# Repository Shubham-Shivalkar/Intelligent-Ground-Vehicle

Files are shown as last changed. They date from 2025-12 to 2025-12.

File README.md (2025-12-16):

# Intelligent-Ground-Vehicle
Intelligent Ground Vehicle (IGV) is an autonomous rover developed for ROBOFEST Gujarat, designed to navigate complex terrains using a modified rocker suspension and ROS2-based autonomy. It integrates LiDAR, RGB-D vision, GNSS, and SLAM for reliable, collision-free navigation

📌 Overview

The Intelligent Ground Vehicle (IGV) project focuses on the design and development of an autonomous rover capable of navigating complex, unstructured terrains with minimal human intervention. Developed for the ROBOFEST Gujarat – Ground Vehicle Category, the rover demonstrates robust mechanical design, advanced perception, and autonomous navigation using ROS2-based software architecture.
This project addresses real-world challenges in autonomous navigation, where robots must operate reliably in cluttered, constrained, and dynamic environments, such as disaster zones, agricultural fields, and outdoor terrains.

🎯 Objectives
- Design a stable and lightweight rover platform for rough terrain traversal
- Achieve collision-free autonomous navigation across multi-stage obstacle courses
- Integrate sensor fusion, SLAM, and path planning using ROS2
- Validate performance through simulation (Gazebo + RViz) and real-world testing

  🏁 Competition Context

The Ground Vehicle Category consists of four progressive stages, each increasing in obstacle density and terrain complexity. Performance is evaluated based on:
- Collision-free navigation success rate
- Shortest traversal time
- Autonomy, robustness, and reliability
  
🛠️ Mechanical Design

- Suspension System: Modified Double Rocker Mechanism
- Chassis Material: Aluminum Alloy 6063-T6 (extrusion grade)

- Dimensions:

  - Length: 83.8 cm

  - Width: 69 cm

  - Height: 60 cm

- Terrain Capability:

  - Climbs slopes up to 45°
  - Maintains continuous wheel–ground contact
- Validation:
  - FEA confirms max deformation ≈ 0.0012 mm
  - Factor of Safety: 2.0 – 2.5
    
⚙️ Electronics & Sensors

- Low-Level Controller: Custom ESP32-S3 PCB

- High-Level Computer: NVIDIA Jetson Orin Nano

- Sensors:

  - YDLIDAR G2 (360° LiDAR)

  - Intel RealSense D435i (RGB-D + IMU)

  - MPU-9250 (9-axis IMU)

  - GNSS (u-blox M10)

  - Wheel Encoders (600 PPR)

🤖 Software Architecture

- Framework: ROS2

- Core Modules:

  - Sensor fusion (EKF)

  - 2D/3D SLAM (Cartographer, RTAB-Map)

  - Navigation stack (Nav2)

- Operating Modes:

  - Manual (PS5 controller)

  - Semi-autonomous

  - Fully autonomous

🧪 Simulation & Digital Twin

A Gazebo-based digital twin was developed to validate:

- Line following (Stage 1)

- Obstacle avoidance

- Ramp climbing

- Dynamic obstacle handling

Visualization and debugging were performed using RViz2 and RQT.

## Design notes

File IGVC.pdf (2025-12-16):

- Type of Robot: Autonomous Rover[IGV]
- Link of CAD : https://drive.google.com/drive/folders/1Fbs--0POYBewVTIGlXbTmj3GZvEJPO7q
- Robot Assembly Design (Proposed Diagram): Drawing each part of the robot is preferred as an attachment. (CAD drawings are preferred) (400 words)
NASA’s Mars missions demonstrated the versatility of the rocker-bogie in Curiosity and Perseverance, and by following the detailed guidelines and tasks provided by GUJCOST, we reengineered the concept into a 4-wheel rover with a rocker-type suspension and a differential stabilizer bar. This configuration reduces weight and kinematic complexity while preserving terrain adaptability, enabling traversal over hard rock, loose soil, and slopes up to 45°. The stabilizer minimizes chassis roll, ensuring continuous wheel–ground contact, higher traction efficiency, and a stable platform for autonomous sensing and navigation.
- The rocker mechanism consists of two rocker arms joined at a central pivot, designed at a 90° orientation to minimize induced stresses during terrain traversal.
- The overall dimensions of the rover are 83 × 68 × 60 cm (L × W × H), making it compact yet stable for IGVC field navigation.
- This geometry distributes loads evenly, reducing strain concentration and chances of permanent deformation in the chassis.

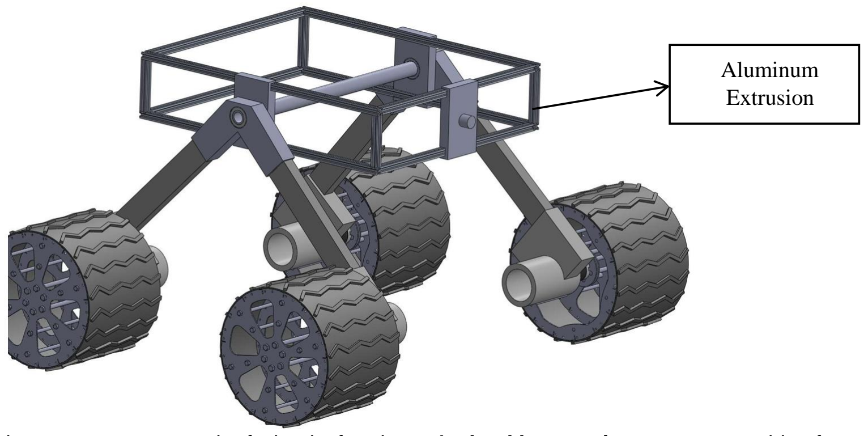
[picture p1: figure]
Aluminum Extrusion

- Each rocker arm supports a pair of wheels, forming a 4-wheel locomotion system capable of negotiating ramps, bridges, and uneven terrain.
- The two rockers are connected via a differential stabilizer bar, which balances the motion between left and right sides.
- The stabilizer ensures that when one side rises over an obstacle, the opposite side compensates, keeping the chassis level
- This enhances stability on slopes up to 45°, critical for ramps and dual incline sections in the IGVC arena.
- The mechanism enables alternate working of both rockers, distributing impact forces and maintaining continuous wheel contact with the ground.
- Reduced chassis oscillation improves sensor accuracy for localization, obstacle detection, and QR/AR code scanning during autonomous navigation.

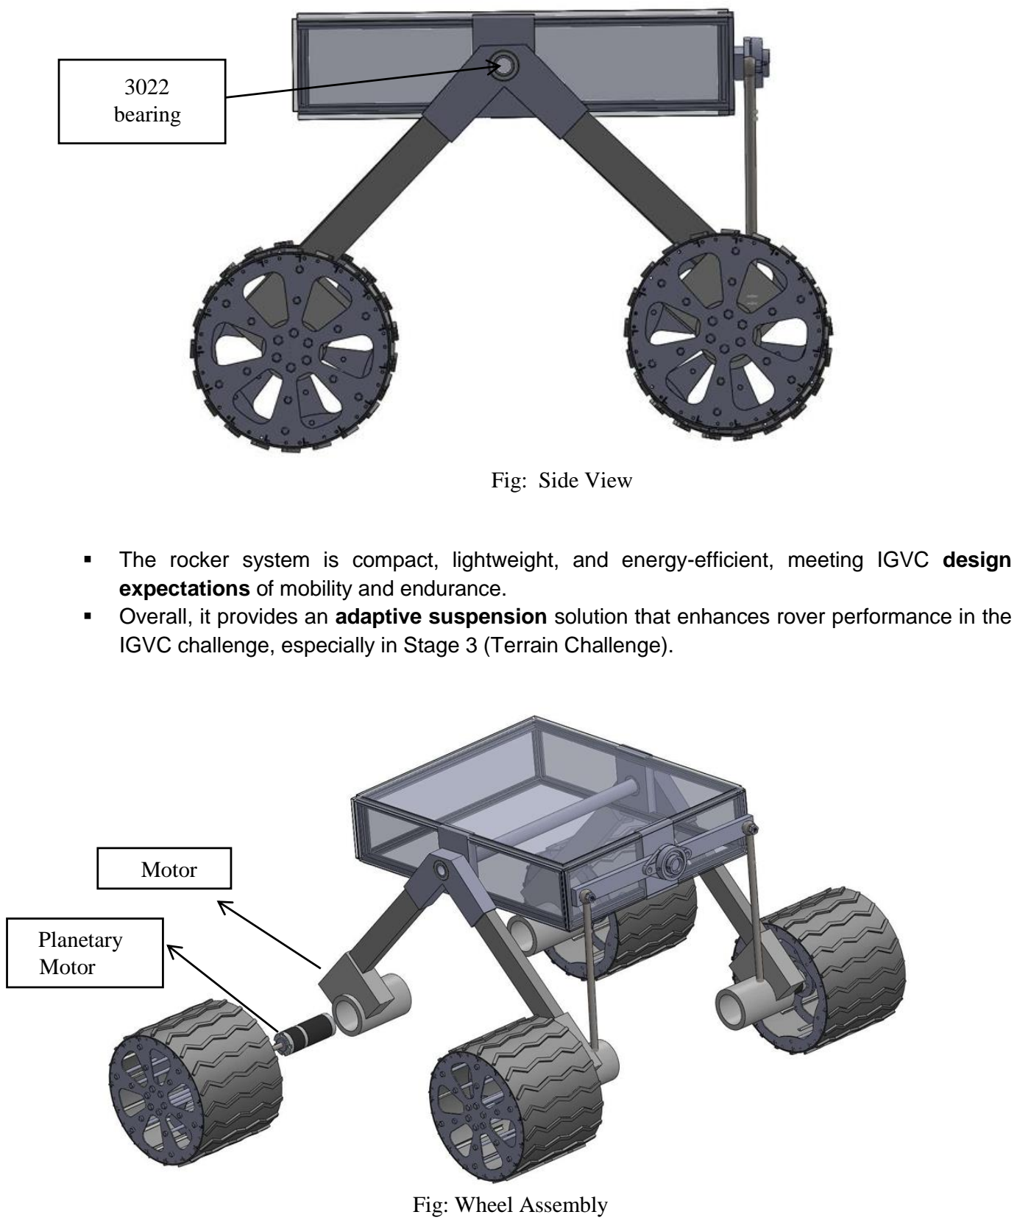
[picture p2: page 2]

Fig: Side View

- The rocker system is compact, lightweight, and energy-efficient, meeting IGVC design expectations of mobility and endurance.
- Overall, it provides an adaptive suspension solution that enhances rover performance in the IGVC challenge, especially in Stage 3 (Terrain Challenge).

Fig: Wheel Assembly

3022
bearing

Motor

Planetary
Motor

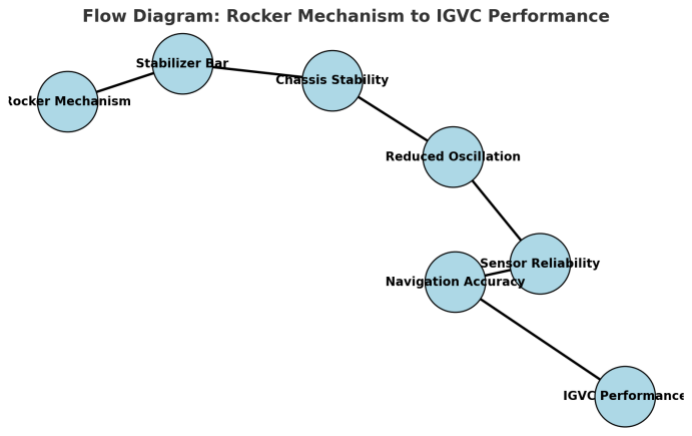
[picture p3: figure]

- Design specifications
- The rover is designed with compact dimensions to maintain stability while fitting within IGVC arena constraints.
- Length (83.81 cm) ensures longitudinal balance, Width (69 cm) prevents toppling, and Height (60 cm) allows mounting of sensors at optimal levels.

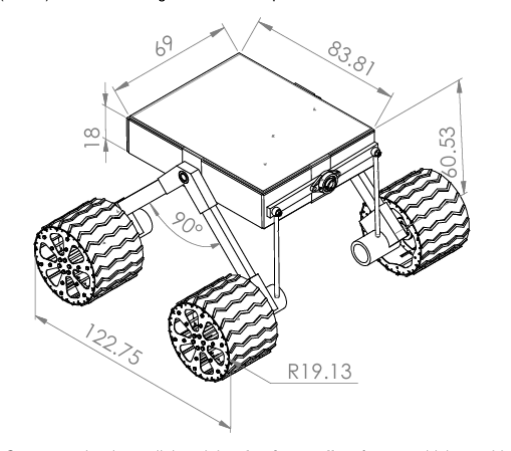
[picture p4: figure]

- Constructed using a lightweight aluminum alloy frame, which provides strength-to-weight efficiency. Integrated with a rocker-stabilizer suspension system for improved terrain adaptability.
- Suspension Mechanism Rocker arms are joined at 90° orientation, connected via a differential stabilizer bar. This ensures one side compensates for the other, reducing oscillations and keeping the chassis balanced.
- The rover can climb and descend ramps with inclines up to 45°, aligning with IGVC terrain requirements. Achieved through optimized torque–weight ratio and suspension design.

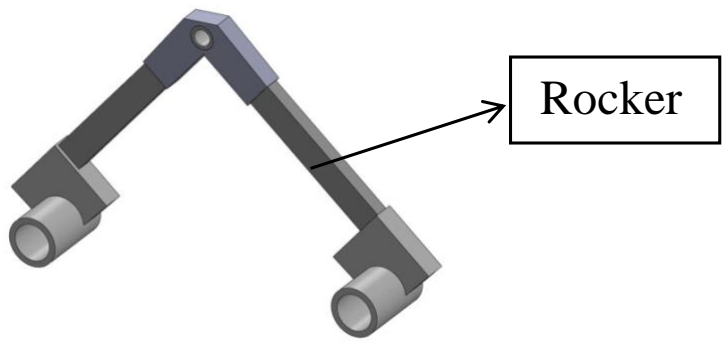
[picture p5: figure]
Rocker

- Differential Stabilizer
- The stabilizer ensures that when one rocker arm lifts (due to terrain), the opposite rocker compensates, keeping the chassis relatively level, It transfers motion from one side to the other using a simple mechanical linkage.
- At the top of the chassis (center), added a horizontal shaft running laterally across this shaft acts as the pivoting differential bar, mounted on bearings to allow free rotation.
- From each rocker arm (left and right), connected a linkage rod to the ends of the differential bar. These linkages are pinned/bolted to allow angular motion.
- When the left rocker rises due to an obstacle, its linkage pushes/rotates the differential bar, this rotation pulls down the right linkage, lowering the right rocker slightly to balance, this equal and opposite motion keeps the main chassis box stable.
- The stabilizer bar and linkages were likely made of mild steel rods, chosen for torsional strength while being lightweight.
- Wheel
- The wheels have an outer diameter of 190 mm and an estimated tread width of 150–180 mm, designed with multi-layer rim rings connected via circumferential plates. A radial spoke arrangement links the hub to the rim, ensuring structural rigidity and even stresses distribution.
- Manufactured from Aluminum Alloy 6063-T6 for high strength-to-weight ratio, corrosion resistance, and machinability.

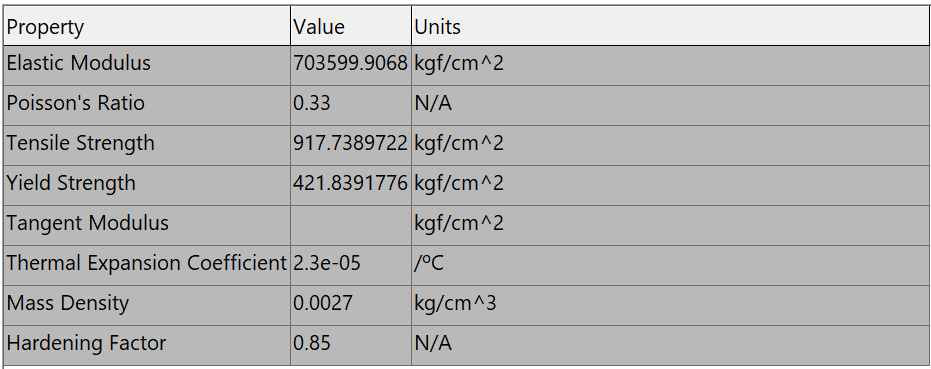
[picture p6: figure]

- Each wheel is estimated to weigh 1.5–2.0 kg, giving a combined mass of 6–8 kg for all four wheels (~15–20% of the rover’s 40 kg). This lightweight design reduces inertia and power consumption, improving overall mobility efficiency.

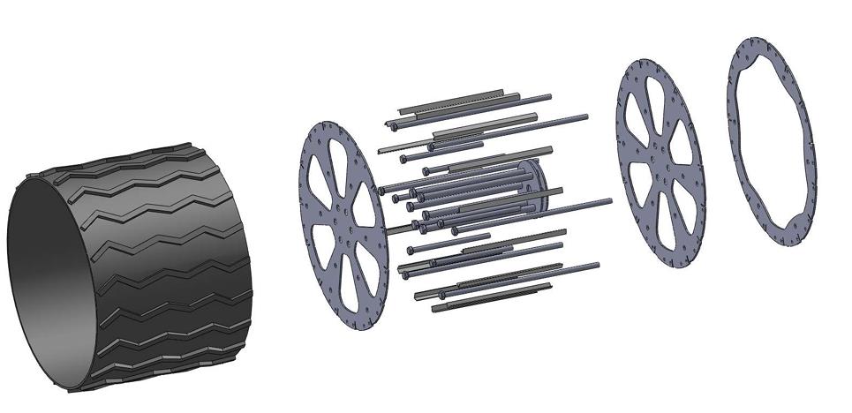
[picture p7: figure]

Fig: Exploded View

- ANSYS simulations indicate a maximum deformation of only ~0.0012 mm under static loading. Each wheel can safely sustain 15–20 kg load, maintaining a Factor of Safety (FoS) of 2.0–2.5 against yielding, making them suitable for rugged planetary environments.
- The cut-outs in rim rings enhance traction and grip on sandy or rocky terrain while reducing slippage. The open-spoke, hollow structure prevents soil/mud accumulation (self-cleaning) and minimizes weight, while the distributed rim design improves shock absorption on uneven surfaces.

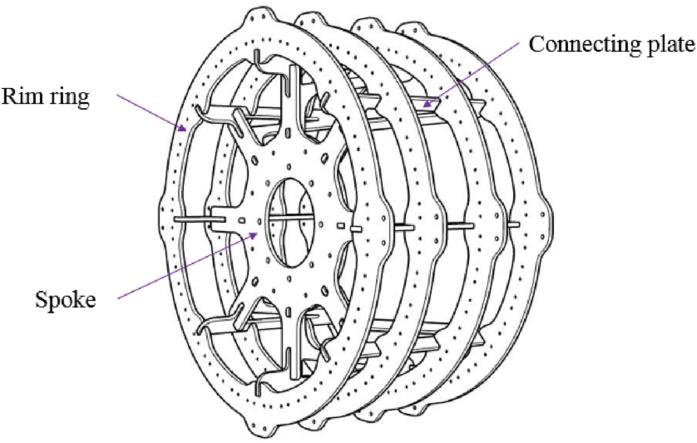
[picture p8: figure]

- Calculations
- Per-wheel loads
For flat ground
N(flat)=mg/4= (40×9.81)/4= 98.1 N
- On 45° slope
N(45)=(mgcos45)/4= 69.37 N | F(∥,45)=(mgsin45)/4= 69.37 N

- Wheel torque requirement (45° climb) Basic torque (per wheel): T(basic)=(F∥,45XRadius) = 69.37×0.125=8.67 N\m Therefore Motor/gearbox sizing: with a 30:1 gearbox, motor torque needed
- Traction requirement for 45° No-slip condition: μ≥(N45)/(F∥,45) = tan45∘=1.0
Design target with margin: μ≥1.2→ justify chevron lugs or rubber tread.

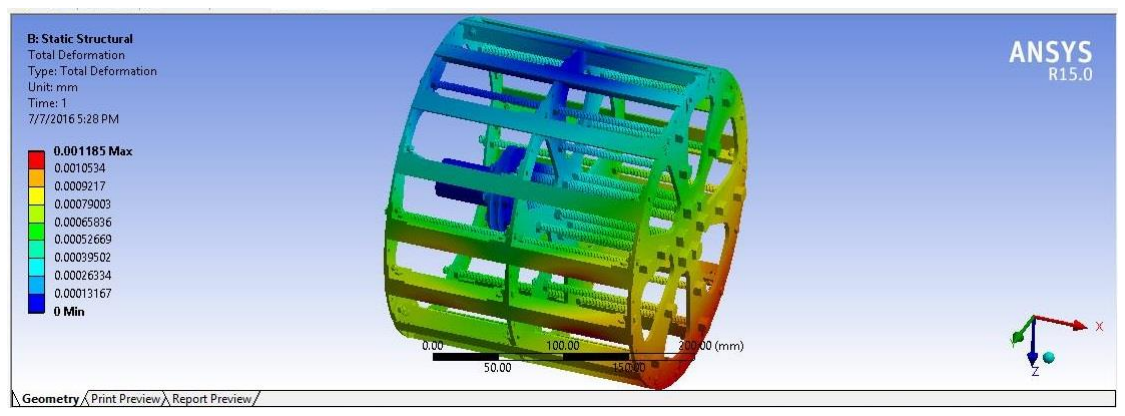
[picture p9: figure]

- FEA shows max deformation ≈ 0.0012 mm under the applied static load — essentially rigid. With Al 6061-T6 (yield ≈ 275 MPa) the peak von Mises stress is < 120 MPa, giving a factor of safety ≈ 2–2.5. This confirms the wheel is stiff, lightweight, and structurally safe for 40 kg rover loads and 45° slope climbing.

¨ Steps to manufacture wheel

- Process: Laser/waterjet cut all rings & plates, deburr, then TIG weld spacers or fasten with M4/M5 screws + Loctite 243
- Jigs: Maintain concentricity using a Ø250 mm dowel-pin jig, keeping TIR ≤0.2 mm.
- Hub: Machine aluminum hub with Ø20 mm bore + 6 mm keyway, and press-fit dual 6004-2RS bearings (H7/g6).
- Finish: Shim plates if axial runout exceeds spec; final balance with M4 trim screws, beadblast and hard-anodize (mask bores/keyway).

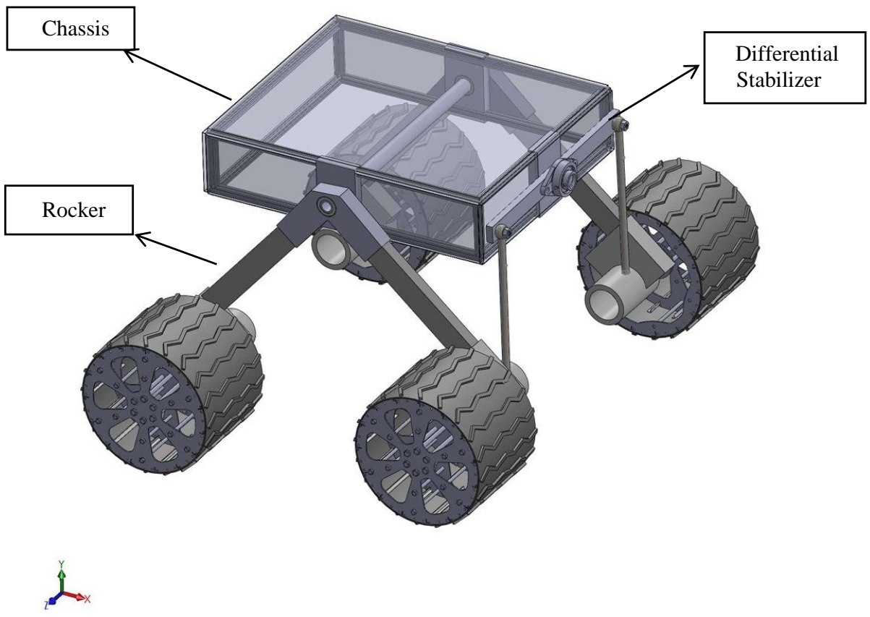
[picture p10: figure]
Differential Stabilizer; Chassis; Rocker

¨ Selection of material is an important step in designing of any component The main advantages of material selection are:
- It increases the reliability of product
- It reduces the cost of product
- It can also optimize the weight of product
- For this design, Aluminum Alloy (Extrusion grade) has been selected due to the following reasons
1. Lightweight compared to steel, which reduces overall system mass and improves mobility
2. Good machinability and weldability, making fabrication easier
3. Corrosion resistance, suitable for outdoor and dusty terrain condition
4. High strength-to-weight ratio (Yield strength ≈ 275 MPa, UTS ≈ 310 MPa)

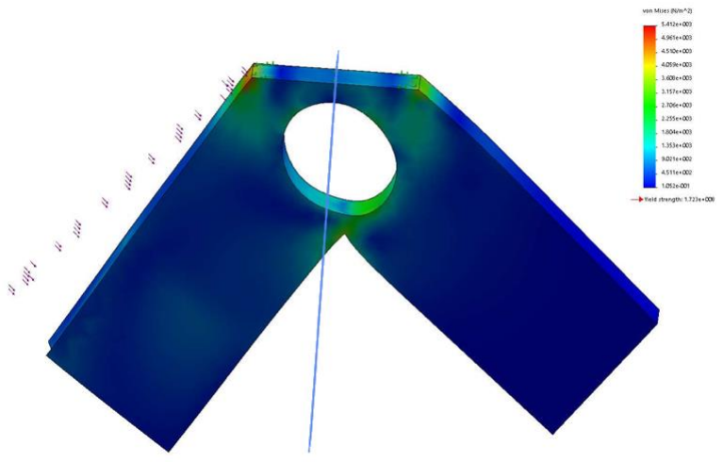
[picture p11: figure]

¨ The material test data of the aluminum extrusion confirms the above properties. Finite Element Analysis (FEA) performed on the rocker mechanism (with plate thicknesses 3/4/3 mm) showed:
- Maximum deformation ≈ 0.0012 mm under static loading → excellent stiffness
- Stress values well below 120 MPa, ensuring safe design against yielding

Thus, Aluminum 6063-T6 extrusion is an optimal balance between strength, weight, and manufacturability for the rover design.

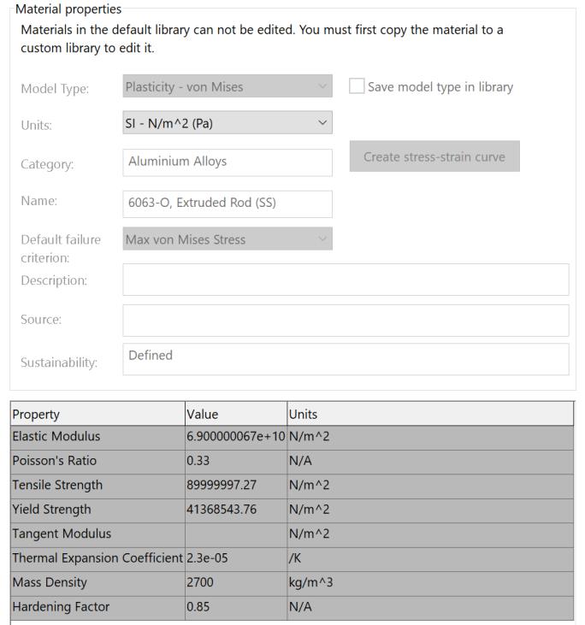
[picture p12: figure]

- Components to be used:
- List of Structure components: Like beams, bushes, shafts, belts, plates, pins, pulleys, wheel, connectors, batteries, motors, etc.
No. | Hardware details | Subsystem | Category | Quantity Need | Specification | Justification for Chosen Type
1 | Motor | Roving Mechanism | Planetary Gear motors | 4 | 12v,96rpm,121.7N-cm | Ease of control Availability
2 | Motor | Roving Mechanism | | 4 | Metal gear Stall torque = 18 kg-cm Operating voltage = 4.8v~6.6v | Ease of control Direction
5 | Chassis material | Chassis | Aluminum extrusion | 15 | Profile size: 2020 Extrusion Length:500mm Material: Aluminum Alloy 6063 | Lightweight and strong material and easy constructible

- List of Motion Components: Like chain, sprockets, flaps, etc.
a. Differential
b. Rocker bogie
c. Bearing
- List of Electronics Components: Like smart ports, switches, joysticks, controllers, LED/LCD screen, power supply, programming components, etc.
Sr. No. | Component | Qty | Price | Vendor
1 | ESP32-S3-DevKitC Development Board | 1 | ₹1,494 | Robu.in
2 | MPU-9250 9-axis IMU Module | 1 | ₹429 | Robu.in
3 | RushFPV GNSS Pro (u-blox M10 GPS) | 1 | ₹1,299 | Quadkart.in
4 | YDLIDAR G2 360° LiDAR (12 m) | 1 | ₹13,124 | Robu.in
5 | Intel RealSense D435i (DepthCam) | 1 | ₹39,783 | Robu.in
6 | 12V DC Geared Motor (250 RPM, 100 N·cm) | 4 | ₹6,657 each | Robu.in
7 | Incremental Rotary Encoder (600 PPR, magnetic) | 4 | ₹3,022 each | Robu.in
8 | Cytron MD10A 10A Motor Driver | 4 | ₹2,500 each | Cytron / Robu (dual channel MDD10A)
9 | NVIDIA Jetson Nano 4GB Module | 1 | ₹13,158 | Robu.in
10 | 7.5″ E-Ink Display (640×384) | 1 | ₹5,459 | Robu.in
11 | Misc electronics (headers, PCB, etc.) | 1 | ₹2,000 | –
- List of Other Accessories: Clothes, plastic eyes/ear/feeling like real all external components which are for the look.

- The methodology of Making Robot: (Please write Entire Technical Specifications of Proposed Robot with brief notes and diagrams) (400 words)

¨ Custom ESP32-S3 MCU Board

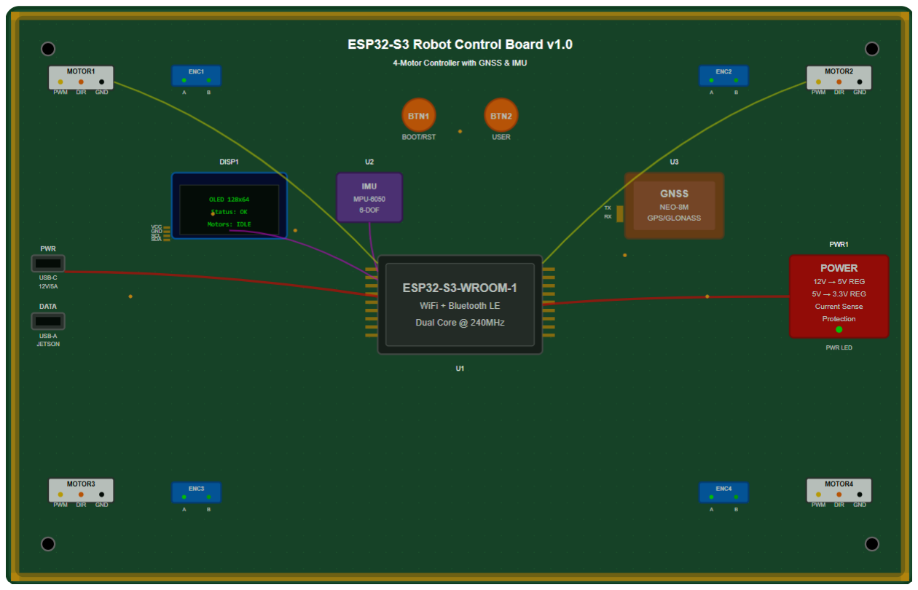
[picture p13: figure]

¨ We will design a compact custom PCB around the ESP32-S3 chip to integrate all low-level electronics. The PCB is approximately 10×5 cm (2-layer) and includes:

- Motor Driver Connectors (4×): Each provides 12 V, two PWM signals, two DIR signals, and ground to drive one MD10A channel.
- Encoder Inputs (4×): Each has VCC, GND, and two signal lines (A, B) for quadrature encoders.
- GNSS/UART Header: A 6-pin connector (VCC, GND, TX, RX, SCL, SDA) for the RushFPV GPS (UART for NMEA, I²C for compass).
- I²C Header: 4-pin header (VCC, GND, SCL, SDA) for the IMU and OLED (shared bus).
- Button Inputs (2×): Two GPIO pins with pull-ups to read user pushbuttons (mode select, emergency stop).
- Power & Boot: A 5 V regulator (buck) feeds the ESP32 and sensors; a connector for the 12 V battery input; jumpers/solder pads select battery charging vs. direct power. The board can also supply 5 V to the Jetson USB power if needed.
- The board includes an OLED display showing system status (GPS fix, mode, battery voltage) and indicator LEDs for boot/BLE status. The ESP32 firmware runs PID loops for motor velocity control using encoder feedback (tuned for ramp ascent in Stage 3). All sensor inputs are timestamped and sent over UART to the Jetson (to minimize wiring).

- PCB Layout & Integration

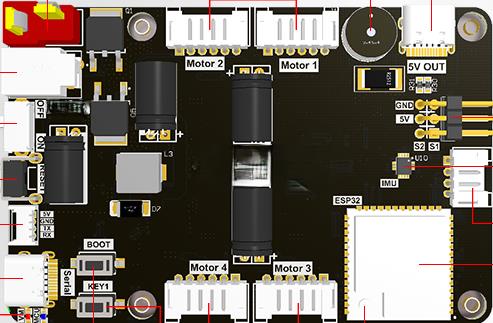
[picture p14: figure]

¨ The PCB layout was designed for robust routing of power and signals. Motor power traces (12 V) are 1 mm wide copper to handle ~10 A. Logic level traces use 0.25 mm width. We placed the ESP32-S3 module centrally, with peripherals grouped logically: motor headers on one edge, encoders on another, power connectors on top, and the OLED/BLE antenna area clear of interference. All high-speed signals (encoder edges, PWM) have short, shielded paths.

¨ Pinout summary: The board breaks out the following interfaces to headers/connectors:

- Motor Driver 1–4 (5 pins each: PWM1, PWM2, DIR1, DIR2, GND, VIN)
- Encoder 1–4 (4 pins each: VCC, GND, A, B)
- GNSS (6 pins: VCC, GND, SCL, SDA, TX, RX)
- I²C Bus (4 pins: VCC, GND, SCL, SDA to IMU/OLED)
- Buttons (2 pins with GND)
- Power Input (12 V, GND) and 5 V Out for Jetson. This layout allows the Jetson Nano (now Orin Nano) to connect via a short cable to the board’s UART and USB ports for data/power.

¨ Citing the ESP32 board functionality: it indeed ―gathers sensor data and runs a motorcontrol PID,‖ and it ―provides connectors for MPU-9250 IMU, GNSS Pro GPS, wheel encoders, motor drivers, an OLED, and push-button inputs. The power section provides 12 V to motors and regulated 5 V to the logic

- Electronics Hardware and Sensor Selection

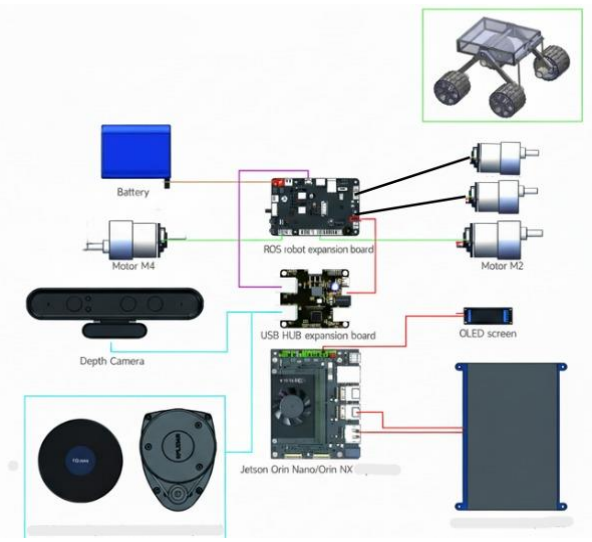
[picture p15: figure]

- Custom ESP32-S3 MCU board: The on-board microcontroller is an ESP32-S3 (chosen for its built-in Wi‑Fi, Bluetooth and AI acceleration). It gathers sensor data and runs a motorcontrol PID. The board provides connectors for:
- MPU-9250 IMU (×1): 9-axis inertial sensor (gyro/accel/magnetometer) with I²C interface (VCC, GND, SCL, SDA).
- Rush FPV GNSS Pro (×1): GPS/GNSS module with u‑blox M10 chip (supports GPS, GLONASS, Galileo, BeiDou concurrently at up to 10 Hz). This multi-constellation support ensures robust outdoor positioning. (Its connector has VCC, GND, SCL, SDA, TX, RX.)
- Wheel encoders (×4): Each DC motor has an incremental encoder; board hosts 4 connectors (VCC, GND, A, B) to read encoder A/B channels. High-resolution (600 PPR) encoders yield precise odometry.
- Motor driver headers (×4): For each wheel, 5-pin connector to Cytron MD10A (GND, PWM1, PWM2, DIR1, DIR2) for bidirectional PWM drive.
- OLED display: A small onboard OLED (VCC, GND, SCK, SDA) shows status.

- User buttons (×2): Two push-button inputs for mode/control.
- Power supply: Onboard DC-DC regulator converts battery 12 V to 5 V for MCU and sensors; also provides unregulated 12 V out to motor drivers (bypassing regulator) as part of the BMS design.
- Single-board computer: NVIDIA Jetson Orin Nano 4 GB (supports Linux + ROS2, GPUaccelerated AI). It runs ROS2 and high-level processing.
- Intel RealSense D435i depth camera (×1): Provides synchronized depth (to ~10 m) and color images; includes a built-in IMU. The IMU in D435i assists SLAM by giving motion data. USB3 interface to Jetson.
- YDLIDAR G2 2D LiDAR (×1): 360° laser scanner, 12 m range, 360° FOV, up to 5 kHz update. Chosen for full-plane obstacle detection with good range and ambient-light resistance 9 (https://cdn.robotshop.com/media/y/ydl/rb-ydl-05/pdf/ydlidar-g2-360-laser-scanner-datasheet.pdf) . Connects via UART (USB/serial).
- 7.5″ Display (e-ink): Low-power screen (640×384) for status/GUI.
- Compass (HMC5883) on GPS module: Provides heading.
- Component Justification:
- ESP32-S3: Integrates dual-core MCU plus Wi-Fi/Bluetooth, enabling wireless debugging/logs and future IoT connectivity. On-chip tensor accelerator could be used for lightweight ML.
- Rush GNSS Pro (M10): Latest u-blox M10 chipset supports multiple GNSS (GPS/GLONASS/Galileo/ BeiDou) and up to 10 Hz fixes, giving improved accuracy and faster updates than older modules.
- MPU-9250 IMU: Established low-cost 9-DoF IMU for inertial data (complementing depth camera IMU).
- Intel RealSense D435i: A high-fidelity RGB-D camera with global shutter and on-board IMU, ideal for outdoor 3D mapping and visual SLAM. It offers up to 1280×720 depth at 90 fps, with wide FOV.
- YDLIDAR G2: Affordable 360° planar LiDAR with 12 m range 9 (https://cdn.robotshop.com/media/y/ydl/rb-ydl-05/pdf/ydlidar-g2-360-laser-scanner-datasheet.pdf) , suitable for both indoor/outdoor obstacle detection. Its class-1 laser is eye-safe, and robust motor/optics yield stable scans. 360° coverage is useful for localization.
- Cytron MD10A motor driver: Capable of continuous 10 A per channel, easily driving 12 V high-torque motors.

- In addition to the ESP32 board, the robot uses a NVIDIA Jetson Orin Nano (8 GB) single-board computer for high-level processing, replacing the earlier Jetson Nano. The Orin Nano’s Ampere GPU delivers up to 67 TOPS of AI performance (Sparse INT8)[7], (https://developer.nvidia.com/blog/nvidia-jetson-orin-nano-developer-kit-gets-a-super-boost/) vastly outpacing the Nano, enabling real-time neural networks on camera data. Connected to the Jetson (via USB/serial) are: - Intel RealSense D435i (RGB-D camera): Provides synchronized depth (to ~10 m) and RGB images, plus a built-in IMU. This will handle visual tasks: line detection, QR decoding, and scene understanding.
- YDLIDAR G2 360° (2D LiDAR): A 360° planar laser scanner (12 m range, up to 5 kHz) for obstacle detection and mapping. Its full horizontal coverage and ambient-light immunity make it ideal for SLAM and obstacle avoidance outdoors.
- 7.5″ E-Ink Display: Low-power status display (640×384) mounted on the chassis, driven by the ESP32 (for mode/status readout).
- The D435i’s RGB camera will serve double duty: detecting the course line in Stage 1 and reading QR/AR markers in Stage 4 (using on-board neural nets or OpenCV). An additional narrow-field camera could be added for higher-speed line following if needed, but the RealSense already provides a wide-angle color image. A small compass (HMC5883) on the GPS module gives a coarse heading if required.
- Our sensor suite (IMU, GPS, encoders, LiDAR, depth/RGB camera) covers all navigation needs. For example, indoor-outdoor SLAM can fuse LiDAR and vision; outdoors the GPS provides a global fix. The ESP32’s on-chip neural engine could also run lightweight ML (e.g. gesture recognition or sensor anomaly detection) ifdesired.

- Software Architecture & Data Flow

¨ Data flow: On ESP32-S3, sensor readings (IMU, wheel encoders, GPS, OLED status) are timestamped and packaged into serial packets. These packets are sent over UART to the Jetson Nano. On the Jetson, a custom ROS2 node (Python/C++) reads UART and publishes sensor topics: /imu/data (sensor_msgs/Imu), /odom (nav_msgs/Odometry from encoders), /gps/fix (NavSatFix), /scan (LaserScan from YDLidar), and /depth/points or /depth/image_raw (PointCloud2 from D435i).

¨ Sensor fusion & TF: A ROS2 robot_localization EKF node fuses wheel odometry and IMU data to produce smooth odometry (/odometry/filtered) 10 (https://automaticaddison.com/sensor-fusion-using-the-robot-localization-package-ros-2/#:~:text=,msg) . Static transforms ( /tf_static ) are broadcast from fixed frames: chassis to sensor mounts. The robot_state_publisher (with joint states, if any) publishes all link transforms on /tf (dynamic) and /tf_static (fixed) 11 (https://automaticaddison.com/sensor-fusion-using-the-robot-localization-package-ros-2/) . This yields a full TF tree (e.g. map odom base_link sensors).

¨ Visualization: Topics /imu/data , /odom , /scan , and /depth/points can be visualized in RViz2. IMU and odometry give orientation and position, LiDAR scan is shown as 2D obstacles, and depth camera data as pointcloud.

¨ SLAM (2D vs 3D): Initially, standard 2D SLAM algorithms will be used to build maps:

- Cartographer, Gmapping, slam_toolbox (ROS2-compatible), which operate on 2D LiDAR ( /scan ). For 3D mapping with the depth camera:
- RTAB-Map (RGB-D SLAM) can use the D435i’s depth+RGB+IMU to build 3D maps (pointclouds).
- ORB-SLAM2/3 or LSD-SLAM (visual SLAM) could use the RealSense images for sparse SLAM (monocular/stereo). These are ―vSLAM‖ approaches mentioned (we would research ORB-SLAM3 for RGB-D use).

¨ Localization: During navigation, the fused odom & IMU and recent SLAM map yield a pose (via amcl on 2D or visual-odometry). A navsat_transform node can fuse GPS fixes to correct drift and publish a /fix or a transform to global (geo) coordinates.

¨ Autonomous Navigation: For 2D nav on a flat map, ROS2 Nav2 (Navigation Stack) will plan and follow paths using /scan and /odom . For 3D point-cloud navigation (outdoor/open), one could research extensions like Move3D or using OctoMap from /depth/points . (This is an active research area; potential methods include costmaps generated from heightmaps or using the depth data as obstacle warnings).

¨ AI/Computer Vision: The Jetson Nano enables onboard AI: running a neural network (YOLO/ tensorRT) on camera feed to detect obstacles or targets. Machine learning (pointcloud clustering, ground plane segmentation) could enhance obstacle detection beyond raw SLAM. (With ROS2 on Jetson, vision pipelines for object recognition or terrain classification can be integrated.)

¨ The data flow in Manual mode is direct: joystick commands from a BLE-connected PS5 controller (handled by the ESP32) bypass most autonomy and drive the wheels. In Semi-autonomous mode, camera video streams (compressed) and telemetry are sent to a base station, where a user may teleoperate or monitor. In Autonomous mode, goal waypoints and courses are fed into Nav2. All modes use the same sensor pipeline, but behavior differs.

- Key SLAM & Nav Choices

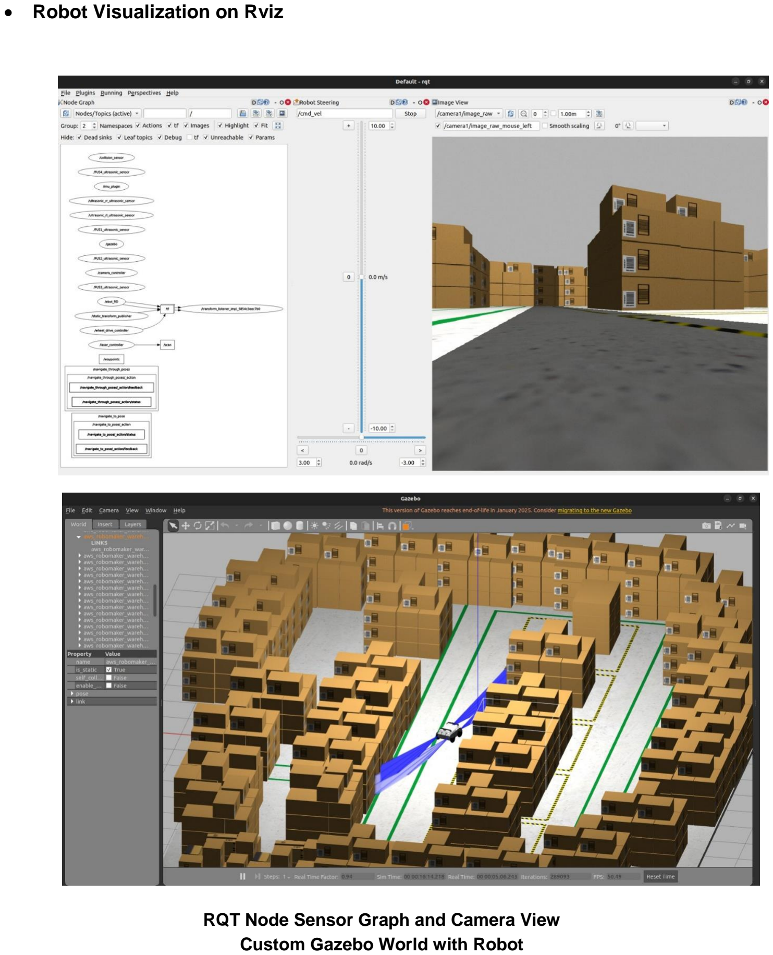
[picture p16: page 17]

- Robot Visualization on Rviz

RQT Node Sensor Graph and Camera View Custom Gazebo World with Robot

- SLAM algorithms:
- 2D: Cartographer and Gmapping (2D lidar SLAM), and SlamToolbox (incremental and offline 2D mapping) are candidates for planar mapping.
- 3D: RTAB-Map (RGB-D SLAM with loop closure) is a mature choice for depth-camera 3D maps. For purely visual SLAM, ORB-SLAM2/3 or VINS-Mono (monocular + IMU) can be explored.
- Nav2: ROS2 Nav2 (the successor of move_base) will be used for standard 2D waypoint navigation on an occupancy map.
- Topic outputs: All sensor outputs (/imu, /odom, /scan, /depth/points, /fix) are published on ROS2 topics. TF frames (mapodombase_link) are broadcast (static transforms from robot_state_publisher ). Rviz2 can then display: sensor data, robot model, and map.
- RQt Graphs: The ROS node graph (RQt) will show nodes/publishers/subscribers for SLAM nodes, publisher of /tf , joint_state_publisher , and Navigation planners. (Placeholder: RQt graph images for 2D, 3D, localization, Nav2 workflows.)
- For mapping and localization, we plan to leverage existing ROS2-compatible SLAM packages: Cartographer or GMapping (lidar-based 2D SLAM) and slam_toolbox (incremental/online mapping) for building a 2D occupancy map. Simultaneously, we can run RTAB-Map (RGB-D SLAM) using the D435i’s depth+RGB+IMU to build 3D pointcloud maps (with loop closure). Visual SLAM options (ORB-SLAM2/3 or VINS-Mono) could be explored if needed. During navigation, the fused odometry provides the robot’s pose, and AMCL (Adaptive Monte Carlo Localization) can localize on the 2D map. A navsat_transform node can optionally fuse GPS fixes into the pose to correct drift.
- For path planning, we use the ROS2 Nav2 stack. Given the 2D map, Nav2 will compute and follow paths using laser scans (/scan) and odometry (/odom)[15]. We will configure behavior tree planners for smooth paths around obstacles. Since the course is mostly flat, 2D navigation suffices; for open outdoor segments we may explore OctoMap (3D occupancy) or height-based costmaps to account for rough terrain. In summary, Nav2 handles the core waypoint navigation (covering Stages 1–4), while our higher-level logic handles stage-specific tasks (e.g. stopping for dynamic obstacles).
- Additional AI / CV Features
- Object Detection: Using the D435i RGB camera and Jetson GPU, run real-time deep learning (YOLO, MobileNet) for object/person detection. Detected obstacles or targets could be published as extra topics (/detections ).
- Terrain Classification: Apply an ML model to camera or lidar data to classify ground vs obstacles (e.g. via a CNN on image or a point-cloud segmentation network).
- Autonomy Enhancement: AI could identify safe paths or goal objects. TensorRT acceleration on Jetson can run lightweight neural nets without hindering SLAM.

- Operating Modes
- Manual Mode (Remote Teleop): The robot can be driven entirely by a human operator using a PS5 DualSense controller connected via Bluetooth to the ESP32-S3. The ESP32 runs a BLE client that receives controller inputs (joystick axes, buttons) and translates them into motor commands (via PWM/DIR pins). This allows full-speed manual control for debugging or hand-run practice. In this mode, the Jetson runs minimal autonomy (just relaying power/status), and the ESP32 directly controls wheel velocities according to the gamepad.

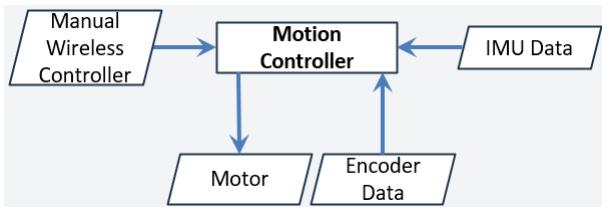
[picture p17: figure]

- Semi-Autonomous Mode (Assisted Remote): The system streams live sensor data (camera view, lidar scan, odometry) to a remote station (via ROS2 topics over Wi-Fi) where a human can monitor progress. The operator can intervene via joystick commands if needed. This is essentially teleoperation with situational awareness. ROS2 topics like /camera/image are published to a remote RViz/GUI. The user can toggle between manual steering or allow autopilot to run, blending modes as necessary.

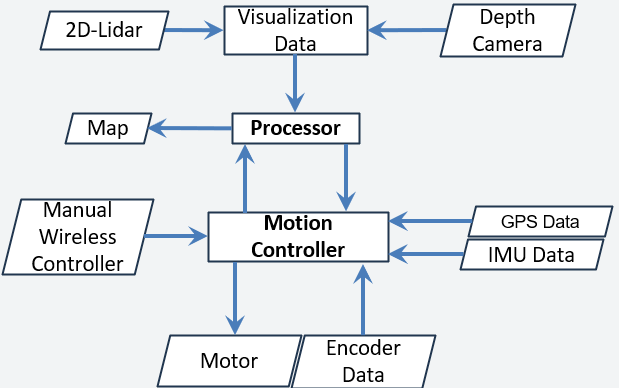
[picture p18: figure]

- Fully Autonomous Mode: In full autonomy, the robot uses Nav2-based navigation to traverse the course. High-level waypoints (preloaded map corners or auto-generated goals) are sent to Nav2, which plans paths around static obstacles. For each stage, the autonomy behavior is specialized: Stage 1 uses vision to lock onto the line, Stage 2 engages obstacle avoidance if lidar sees an obstacle, etc. Additionally, we implement Custom Dynamic Obstacle Handling: if the lidar or camera detects a moving obstacle crossing the path, a ROS2 node commands an immediate stop, monitors until the object clears, then re-issues the goal to resume. Thus, Autonomous mode is Nav2 + stage-specific logic (e.g. stopping logic for the bonus stage).

The data flow in each mode follows ROS2 conventions: sensor drivers → perception/planning nodes → actuator commands. (Diagrams of these workflows would show the sensor topics feeding into ROS2 nodes differently per mode but are omitted here.)

- Simulation & Digital Twin

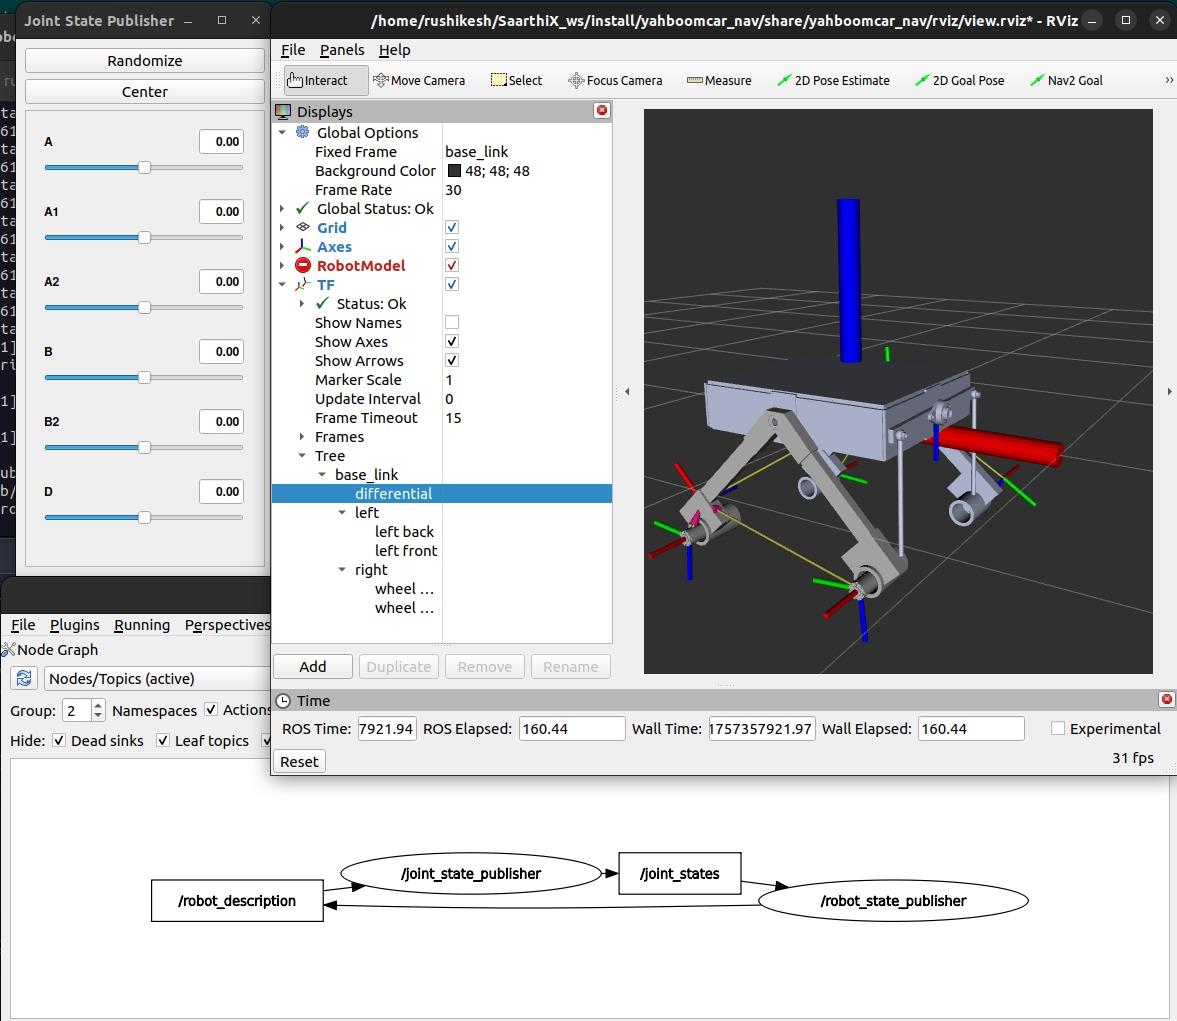
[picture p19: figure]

¨ Digital Twin of Robot

We employ a Gazebo-based digital twin of the vehicle to simulate the entire system before deploying on hardware. The digital model includes realistic dynamics (wheel slip, inertia) and sensor models (simulated RealSense camera and 2D lidar).We launch Gazebo with a custom world (terrain, obstacles, ramps) and run the same ROS2 stack as on the real robot. This allows debugging the navigation and vision pipelines safely. Rviz is run alongside Gazebo to visualize the robot’s perception (mapped obstacles, path plans). Using the Gazebo twin, we can test Stage 1 line following (with a virtual floor line), Stage 3 ramp climbing (with an incline model), and the bonus dynamic obstacle (simulating a rolling ball) without risk.

- Research And Development: We initially designed a conventional rocker–bogie suspension and tested the rover in semi-autonomous mode. However, instability of the main body caused unstable sensor data, leading to errors in autonomous navigation. Major issues also arose in machining and assembly due to the complexity of rocker–bogie joints. To overcome this, we modified the design and developed a new suspension system that is machining-free, requires only basic tools, and allows quick assembly and disassembly. This improved stability, reduced fabrication effort, and enhanced sensor reliability

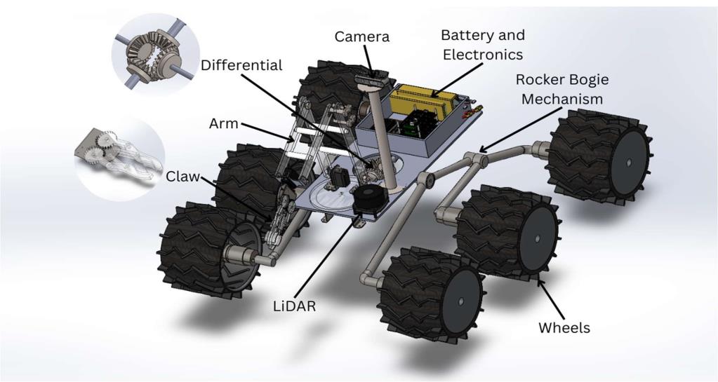
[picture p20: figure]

Fig: 1st Rover

We have Arranged the rocker and bogie in the perpendicular manner so this problem can get solve and one more advantage we get the wheels which were going away from the body are now on their own position this was because of only the modified rocker bogie

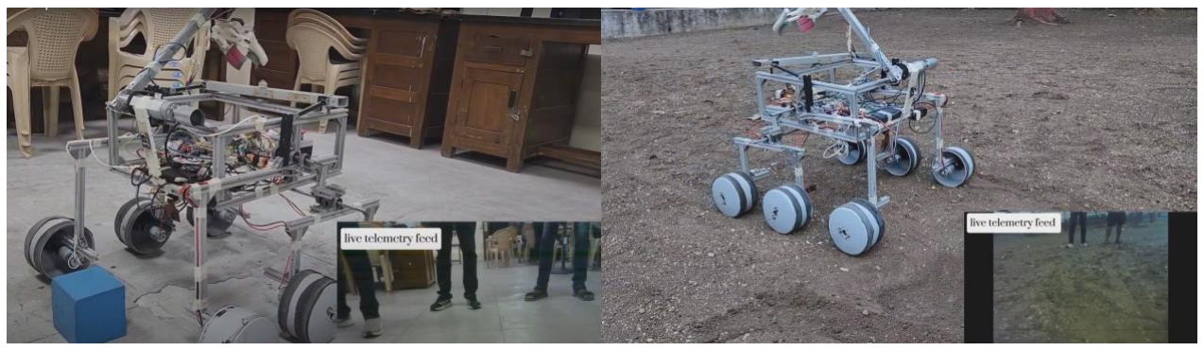
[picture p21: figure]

Fig: Modified Rover

This rover has the capability to traverse terrains with rocks, irregular surfaces, and slopes without transmitting shocks to the main body, ensuring accurate sensor data. We further tested it on rocks with diameters larger than its wheels, muddy surfaces, and for tasks such as soil testing, where the rover was not capable of performing effectively. Therefore, multiple iterations, calculations, and design modifications were carried out, which led to the development of an improved rover system.

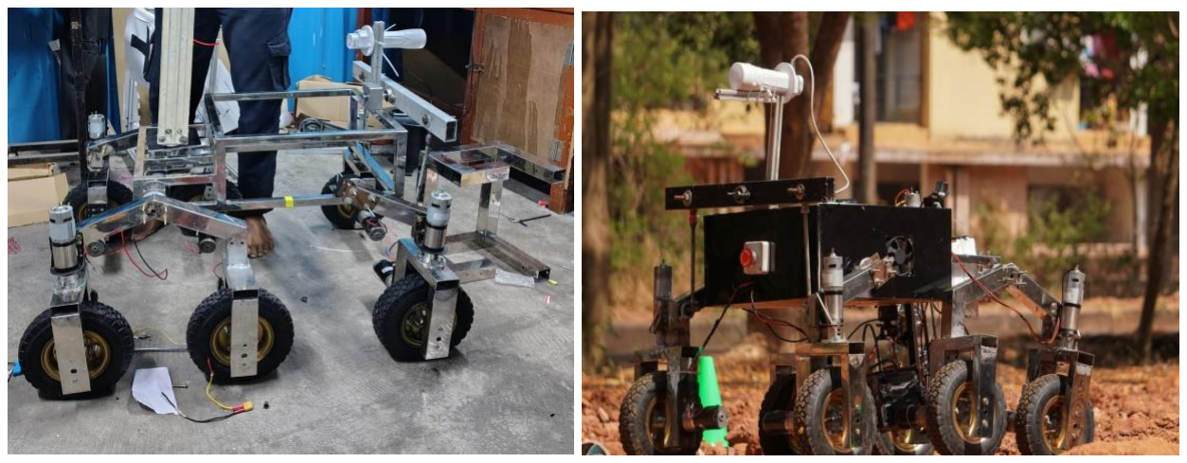
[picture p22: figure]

This rover was capable of traversing varied terrains, slopes, and conditions without getting stuck. However, during a 360° turn, high stresses were generated on the rover segments, limiting turning speed and response. To address this, we explored several solutions and, through a research paper, studied the Double Rocker Mechanism originally designed for four wheels. After simulations and analysis, we developed a modified Double Rocker Mechanism, which resolved the issue and enabled smooth turning. The simulations also confirmed that the rover could traverse 45° slopes, fully satisfying the GUJCOST guidelines

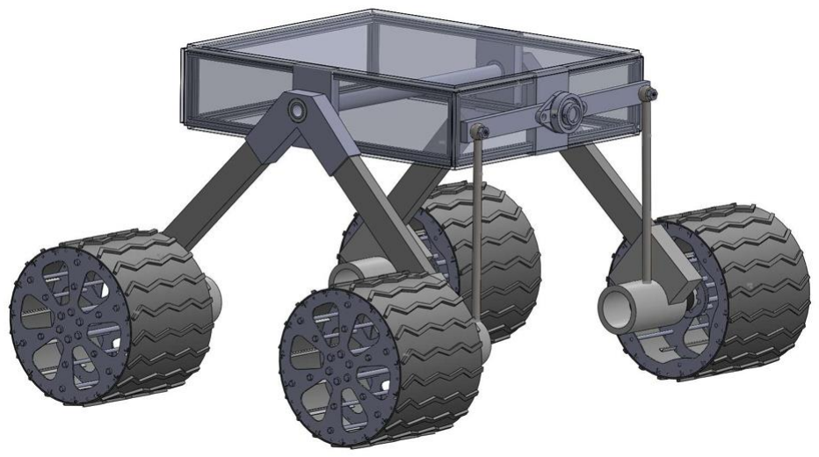
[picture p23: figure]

Fig: Final 4 Wheeled Rover

1. Application of proposed Robot in a societal context: (Not more than 100 words)
he proposed versatile robotic platform addresses critical societal needs. In disaster management, it aids in search, rescue, and debris navigation. For environmental monitoring, it collects real-time terrain and pollution data. In agriculture, it supports precision farming through crop monitoring and automation. Its scope extends to military and defense, enabling surveillance and logistics in hazardous zones. For urban utilities, it assists in infrastructure inspection and maintenance. In remote exploration, it operates in terrains inaccessible to humans, such as mines or extraterrestrial surfaces. Equipped with advanced sensors, GNSS navigation, double rocker suspension, and ROS2, it ensures reliable, autonomous, and adaptable performance.
2. Size of robot proposed for Proof of concept (Small version):
a. Length in 60 cm | b. Width in 55cm | c. Height in 30cm
3. Size of robot proposed as Proto type (Actual Version)
a. Length in 122.75cm | b. Width in 110cm | c. Height in 60.cm
4. Timeline for Robot making with milestones. (Divided in activities vs. no. of days)
Task | Start Week | End Week | Duration (weeks) | Notes
Requirements& CAD Design | 1 | 3 | 3 | CAD replication, sensor mounts
Chassis Fabrication & Assembly | 4 | 5 | 2 | Cutting, welding, finishing
PCB Design &Fabrication | 3 | 4 | 2 | Schematic, PCB layout, prototype fab
Electronics Assembly & Testing | 5 | 6 | 2 | Populate PCB, verify connections
ESP32 Firmware & ROS2 Interface | 4 | 7 | 4 | UART comms, sensor data formats
Sensor Integration (ROS2 nodes) | 6 | 8 | 3 | Publishing /imu, /odom, /scan, / points etc.
SLAM & Localization Setup | 7 | 9 | 3 | Test 2D SLAM (Carto/Gmap), RTAB-Map
Navigation (Nav2) Deployment | 9 | 10 | 2 | 2D Nav on map, obstacle avoidance
Simulation and Validation | 8 | 10 | 3 | Gazebo scenario tests, Rviz demos

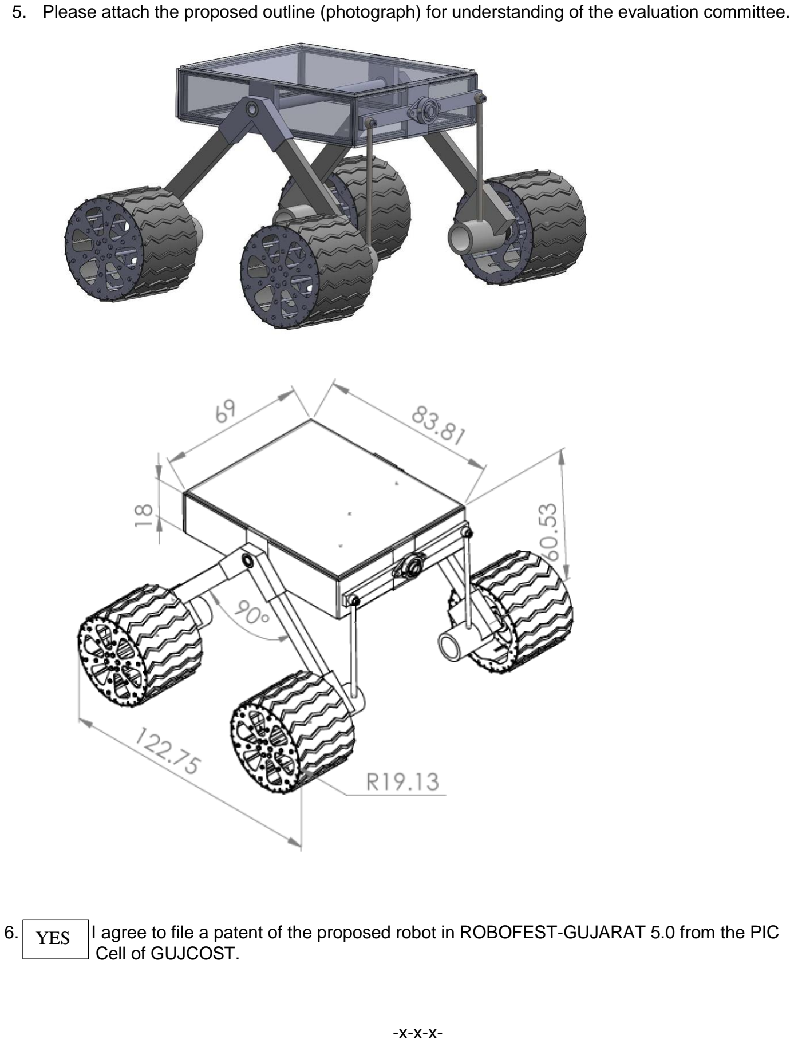
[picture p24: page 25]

5. Please attach the proposed outline (photograph) for understanding of the evaluation committee.
6. I agree to file a patent of the proposed robot in ROBOFEST-GUJARAT 5.0 from the PIC Cell of GUJCOST.

-x-x-x-

YES




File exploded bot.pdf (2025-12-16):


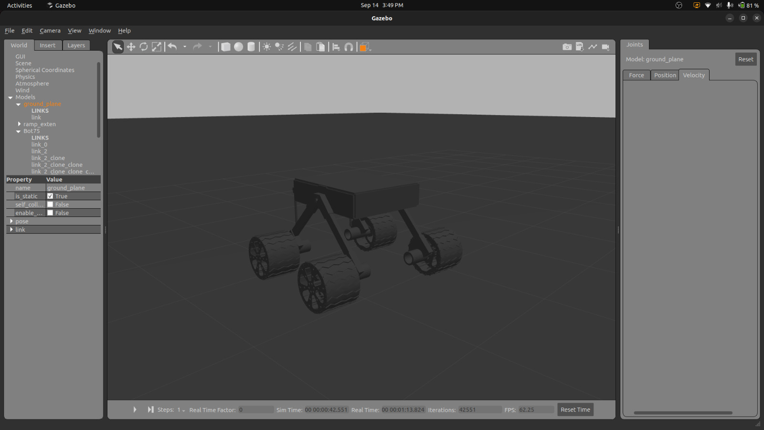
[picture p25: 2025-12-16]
rover gazebo.jpg

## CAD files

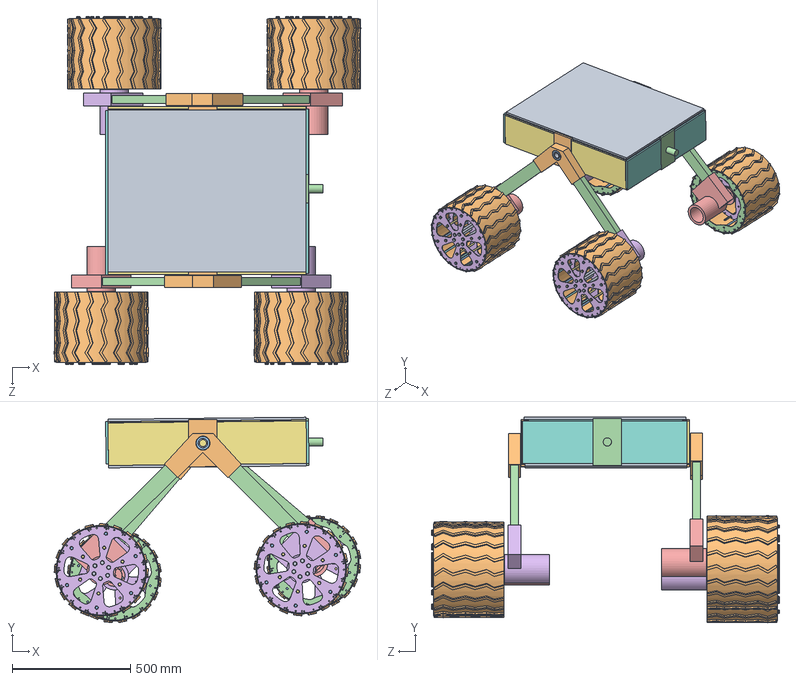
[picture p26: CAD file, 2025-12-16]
rover.SLDASM
1296.4 x 868.8 x 1471.0 mm
stud
joint 2 x 2
bearing x 2
link x 4
motor holder x 2
motor holder right x 2
model (V-Slot 20x20mm) x 4
support x 2
bearing of support x 2
support - 1
Planetary DC Motor x 4
OuterSide x 8
nail_6_100 x 24
corner x 60
nail_8_100 - Copy x 24
Surface x 4
nail_6_200 x 24
OuterSide - Copy x 4
Holder1 x 8
samola x 24
plate x 2
plate 2 x 2
plate3 x 2

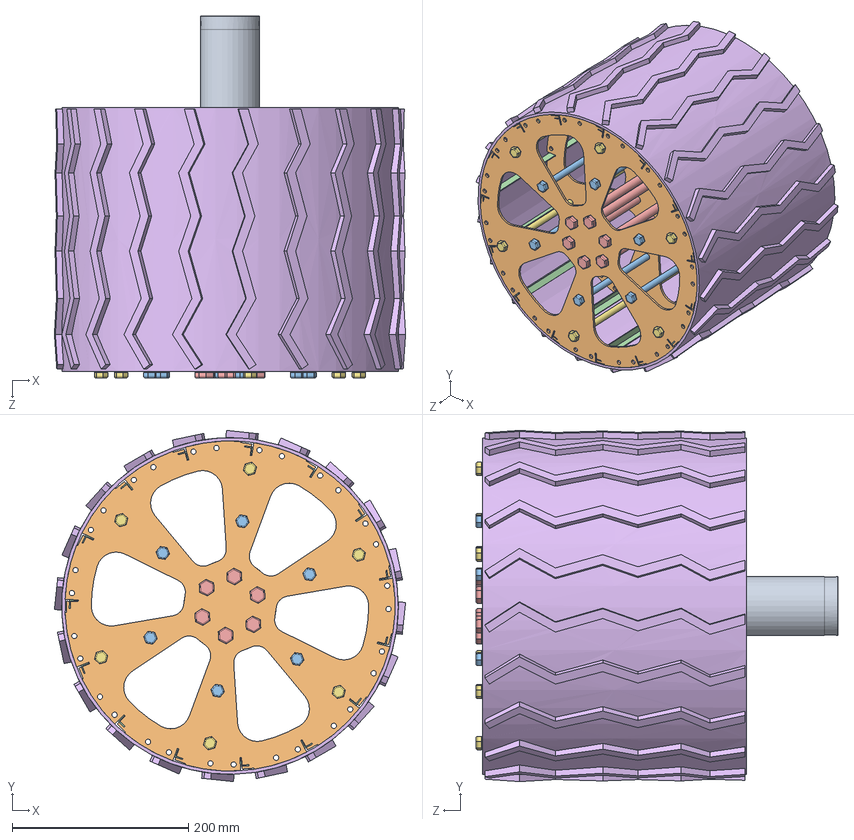
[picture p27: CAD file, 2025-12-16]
Wheel & Motor.SLDASM
399.0 x 399.0 x 411.3 mm
Planetary DC Motor
OuterSide x 2
nail_6_100 x 6
corner x 15
nail_8_100 - Copy x 6
Surface
nail_6_200 x 6
OuterSide - Copy
Holder1 x 2
samola x 6

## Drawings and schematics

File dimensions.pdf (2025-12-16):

B B

2

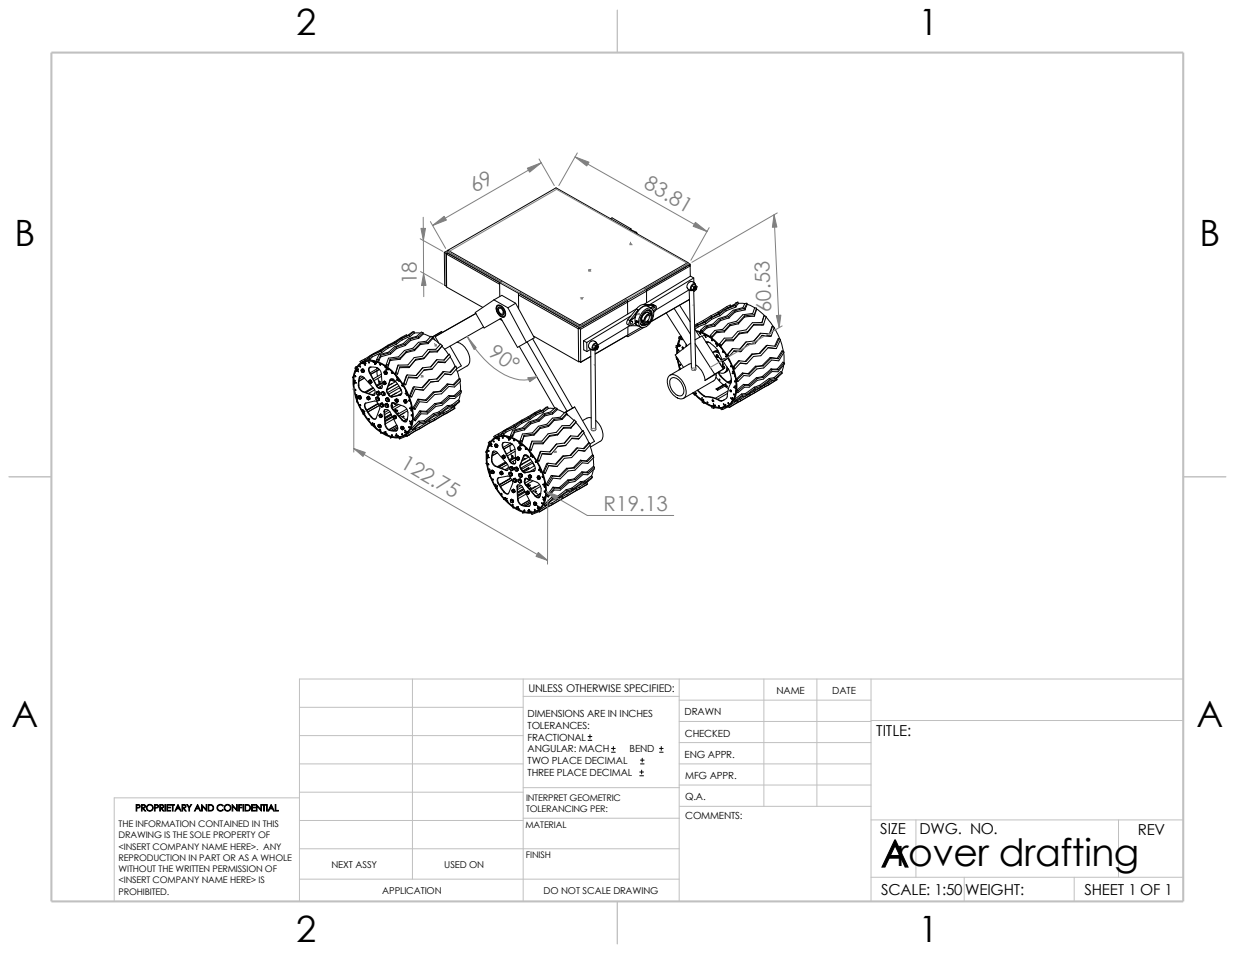
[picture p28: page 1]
COMMENTS:; INTERPRET GEOMETRIC; PROPRIETARY AND CONFIDENTIAL; TOLERANCING PER:

UNLESS OTHERWISE SPECIFIED: | | NAME | DATE

DIMENSIONS ARE IN INCHES TOLERANCES: FRACTIONAL ANGULAR: MACH BEND TWO PLACE DECIMAL THREE PLACE DECIMAL | DRAWN

CHECKED | | | TITLE:

ENG APPR.
MFG APPR.

THE INFORMATION CONTAINED IN THIS
DRAWING IS THE SOLE PROPERTY OF
<INSERT COMPANY NAME HERE>. ANY
REPRODUCTION IN PART OR AS A WHOLE
WITHOUT THE WRITTEN PERMISSION OF
<INSERT COMPANY NAME HERE> IS
PROHIBITED.

MATERIAL | | SIZE A rover drafting | DWG. NO. | REV

NEXT ASSY | USED ON | FINISH

APPLICATION | DO NOT SCALE DRAWING | | SCALE: 1:50 WEIGHT: | | SHEET 1 OF 1
